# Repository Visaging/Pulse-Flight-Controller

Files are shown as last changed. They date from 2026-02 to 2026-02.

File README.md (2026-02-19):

# PULSE Flight Controller
## Why "Pulse"?
The name is inspired by two things I love:
1.  **Pulse Width Modulation (PWM):** The heartbeat signal that powers every motor in this drone.
2.  **Beatbox:** A personal touch (look at the silkscreen artwork on the top layer).

## Overview
Pulse is a completely custom flight controller that was created from the ground up. I designed the whole stack myself to truly understand how a drone works, from the low-level motor mixing logic to the physics of the gyroscope, even though it would have been simpler to simply rely on off-the-shelf hardware and Betaflight. The custom PCB designs and the particular STM32 firmware I wrote to make the silicon work are both included in this repository, which acts as documentation for that process.

## Hardware Stack
* **MCU:** **STM32F405RGT6** - Chosen because it's a beast at math and has enough pins for everything.
* **IMU:** **ICM-42688-P** - Newer and cleaner noise performance than the old MPU6000.
* **Barometer:** **BMP280** - for altitude hold.
* **Gimbal Drivers:** 2x **DRV8313** - integrated directly on the FC.
    * Instead of a heavy separate gimbal controller board, I built the drivers right onto the FC to save weight and space.
* **Power System:** - Redesigned buck converter using **LMR14030SDDAR**.
  * I initially designed it for 6S (25.2V), but realized I wanted headroom. The new design handles up to **40V** input.

## The Firmware
### Key Features:
* **1kHz Control Loop:** A strict real-time scheduler runs the physics engine every 1ms.
* **Quad-X Mixing:** Takes PID output and mathematically mixes it for the 4 motors using **TIM8** (Timer).
* **Interrupt driven I/O:** The Receiver (UART3) and Telemetry (UART4/5) run in the background via Interrupts, so the main flight loop never "freezes" waiting for data.
* **Smart Telemetry:** Streams live voltage, angles, and state to a **Raspberry Pi** companion computer.

### How to Flash It
I added a **USB-C port** and the "Holy Trinity" of buttons (BOOT + RESET) to the PCB so I don't need external dongles.
1.  Plug in USB-C.
2.  Hold **BOOT**.
3.  Click **RESET**.
4.  Release **BOOT**.
5.  Flash the `.bin` file using **STM32CubeProgrammer** (USB DFU Mode).

--- 
<details>
  <summary><h2>PCB Schematics</h2></summary>

</details>

---
<details>
  <summary><h2>PCB Layout and Render</h2></summary>

## Layout
#### Overall:


---
#### Top Layer:


---
#### Layer 2:


---
#### Layer 3:


---
#### Bottom Layer:


---
#### Front Silkscreen:


---
#### Back Silkscreen:


---
## Render
#### Front:


---
#### Back:

</details>

--- 
## Bill of Material

| Item | Description | Quantity | Unit Price ($) | Total Price ($) | URL | Running Total ($) |
| --- | --- | --- | --- | --- | --- | --- |
| PCBA | PCB | 5 PCB, 1 PCBA | $216.41 | $216.41 | https://www.lioncircuits.com/ | $216.41  |
| Tactile Switches  | Boot and Reset Buttons | 2 | $0.0363 | $0.0726 | https://robu.in/product/ts6610tp-160gf-bxg-022-shou-han-50ma-100m%cf%89-100000-times-12v-160gf-round-button-standing-paste-spst-smd-tactile-switches-rohs/ | $216.4826 |
| TYPE-C-31-M-12 | USB-C Port | 1 | $0.42 | $0.42 | https://www.lioncircuits.com/ | $216.9026 |

<details>
  <summary>JLCPCB Order</summary>




</details>
<details>
  <summary>Lion Circuit Order</summary>

final
Lion Circuits_Page_1
</details>
<details>
   
  <summary>Cart</summary>


</details>

## Lessons Learned
* **Power is hard:** My first schematic had a buck converter that would have fried on a 6S battery. Catching that mistake saved the project.
* **Routing matters:** Moving to 4 layers was scary at first, but it solved all my noise and heat issues.
* **Code vs. Reality:** Writing the firmware forced me to verify every single pin connection. I found out that "polling" a receiver is too slow, so I had to learn how Interrupts work.

## License: MIT

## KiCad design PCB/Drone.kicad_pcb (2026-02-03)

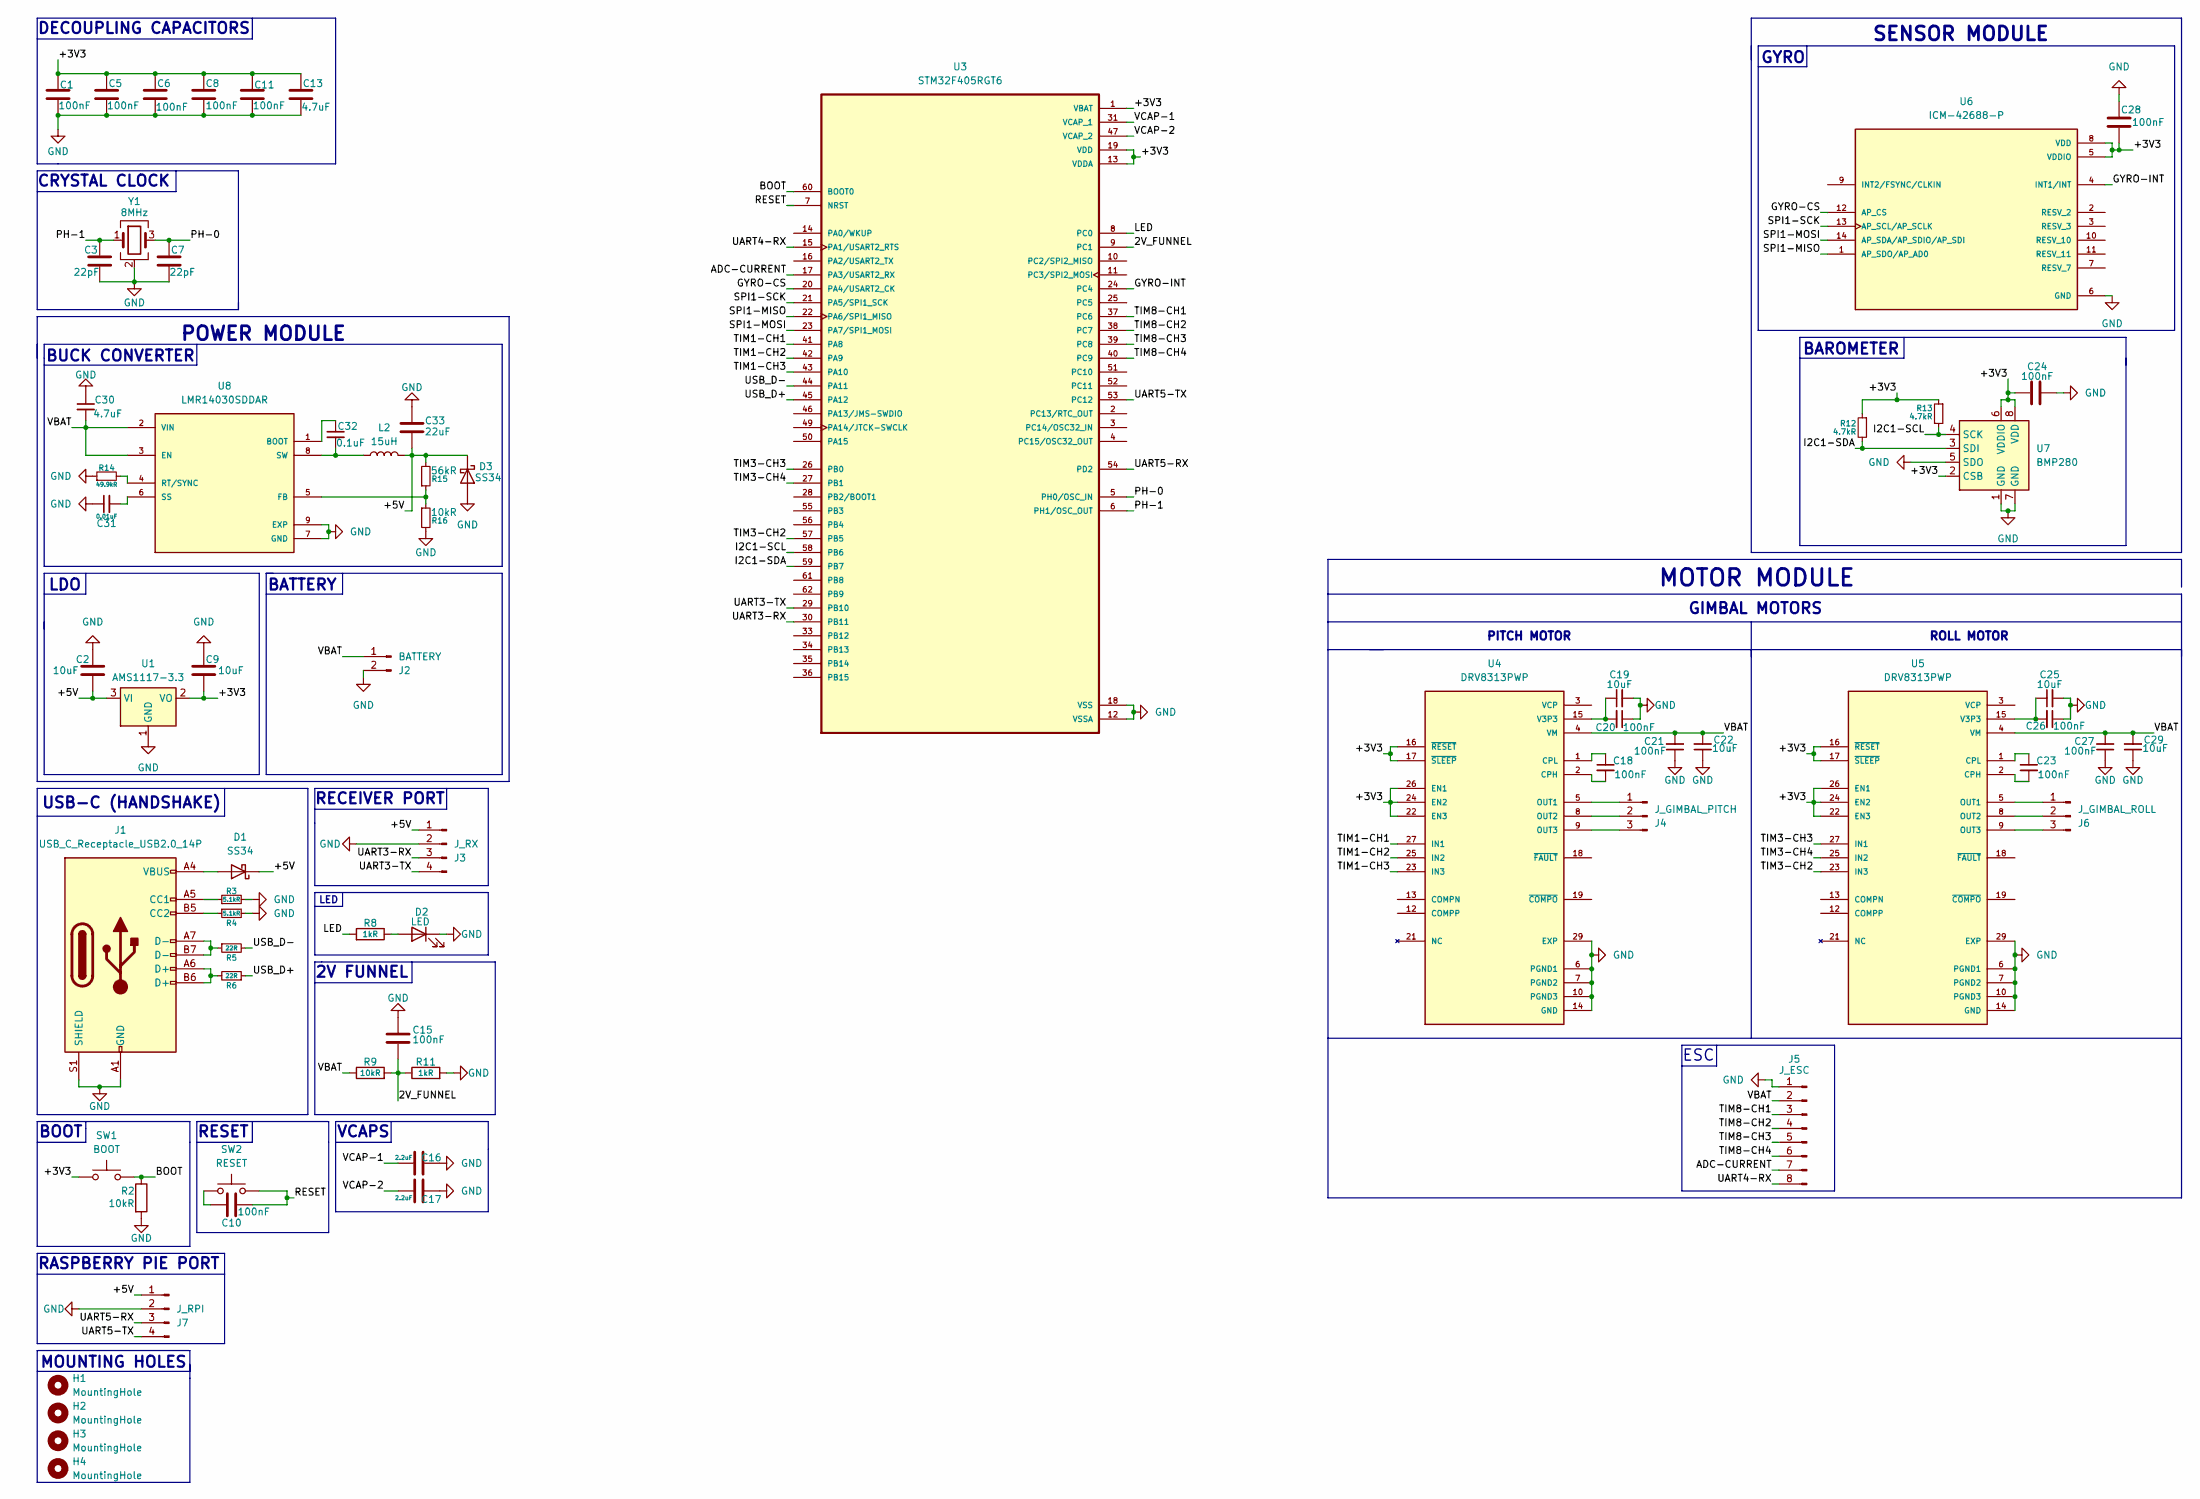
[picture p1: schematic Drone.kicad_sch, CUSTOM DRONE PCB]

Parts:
C1, C5, C6, C8, C10, C11, C15, C18, C20, C23, C24, C26, C28: 100nF; C_0603_1608Metric
C2, C9, C19, C25: 10uF; C_0603_1608Metric
C3, C7: 22pF; C_0603_1608Metric
C13: 4.7uF; C_0603_1608Metric
C16, C17: 2.2uF; C_0603_1608Metric
C21, C27: 100nF; C_1206_3216Metric
C22, C29: 10uF; C_1206_3216Metric
C30: 4.7uF; C_1210_3225Metric
C31: 0.01uF; C_0603_1608Metric
C32: 0.1uF; C_0603_1608Metric
C33: 22uF; C_1206_3216Metric
D1, D3: SS34; D_SMA
D2: LED; LED_0805_2012Metric
H1, H2, H3, H4: MountingHole; MountingHole_3.2mm_M3
J1: USB_C_Receptacle_USB2.0_14P; USB_C_Receptacle_HRO_TYPE-C-31-M-12
J2: BATTERY; SolderWire-2.5sqmm_1x02_P7.2mm_D2.4mm_OD3.6mm
J3: J_RX; PinHeader_1x04_P2.54mm_Vertical
J4: J_GIMBAL_PITCH; SolderWire-0.75sqmm_1x03_P4.8mm_D1.25mm_OD2.3mm
J5: J_ESC; PinHeader_1x08_P2.54mm_Vertical
J6: J_GIMBAL_ROLL; SolderWire-0.75sqmm_1x03_P4.8mm_D1.25mm_OD2.3mm
J7: J_RPI; SolderWire-0.1sqmm_1x04_P3.6mm_D0.4mm_OD1mm
L2: 15uH; L_Bourns_SRN6045TA
R2, R9: 10kR; R_0603_1608Metric
R3, R4: 5.1kR; R_0603_1608Metric
R5, R6: 22R; R_0603_1608Metric
R8, R11: 1kR; R_0603_1608Metric
R12, R13: 4.7kR; R_0603_1608Metric
R14: 49.9kR; R_0805_2012Metric
R15: 56kR; R_0805_2012Metric
R16: 10kR; R_0805_2012Metric
SW1: BOOT; SW_SPST_PTS645Sx43SMTR92
SW2: RESET; SW_SPST_PTS645Sx43SMTR92
U1: AMS1117-3.3; SOT-223-3_TabPin2
U3: STM32F405RGT6; QFP50P1200X1200X160-64N; PARTREV LTR
U4, U5: DRV8313PWP; SOP65P640X120-29N; PARTREV D
U6: ICM-42688-P; PQFN50P300X250X97-14N; PARTREV 1.2
U7: BMP280; Bosch_LGA-8_2x2.5mm_P0.65mm_ClockwisePinNumbering
U8: LMR14030SDDAR; SOIC127P600X170-9N; PARTREV A
Y1: 8MHz; Crystal_SMD_3225-4Pin_3.2x2.5mm

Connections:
/2V_FUNNEL: C15.2, R9.2, R11.1, U3.9 (PC1)
/+5V: C2.2, C33.2, D1.1 (K), D3.1 (K), J3.1, J7.1, L2.2, R15.2, U1.3 (VI)
/ADC-CURRENT: J5.7, U3.17 (PA3/USART2_RX)
/BOOT: R2.1, SW1.2, U3.60 (BOOT0); also elsewhere on the board
/GYRO-CS: U3.20 (PA4/USART2_CK), U6.12 (AP_CS)
/GYRO-INT: U3.24 (PC4), U6.4 (INT1/INT)
/I2C1-SCL: R13.2, U3.58 (PB6), U7.4 (SCK)
/I2C1-SDA: R12.2, U3.59 (PB7), U7.3 (SDI)
/LED: R8.2, U3.8 (PC0)
/PH-0: C7.1, U3.5 (PH0/OSC_IN), Y1.3
/PH-1: C3.1, U3.6 (PH1/OSC_OUT), Y1.1
/RESET: C10.2, SW2.2, U3.7 (NRST); also elsewhere on the board
/SPI1-MISO: U3.22 (PA6/SPI1_MISO), U6.1 (AP_SDO/AP_AD0)
/SPI1-MOSI: U3.23 (PA7/SPI1_MOSI), U6.14 (AP_SDA/AP_SDIO/AP_SDI)
/SPI1-SCK: U3.21 (PA5/SPI1_SCK), U6.13 (AP_SCL/AP_SCLK)
/TIM1-CH1: U3.41 (PA8), U4.27 (IN1)
/TIM1-CH2: U3.42 (PA9), U4.25 (IN2)
/TIM1-CH3: U3.43 (PA10), U4.23 (IN3)
/TIM3-CH2: U3.57 (PB5), U5.23 (IN3)
/TIM3-CH3: U3.26 (PB0), U5.27 (IN1)
/TIM3-CH4: U3.27 (PB1), U5.25 (IN2)
/TIM8-CH1: J5.3, U3.37 (PC6)
/TIM8-CH2: J5.4, U3.38 (PC7)
/TIM8-CH3: J5.5, U3.39 (PC8)
/TIM8-CH4: J5.6, U3.40 (PC9)
/UART3-RX: J3.3, U3.30 (PB11)
/UART3-TX: J3.4, U3.29 (PB10)
/UART4-RX: J5.8, U3.15 (PA1/USART2_RTS)
/UART5-RX: J7.3, U3.54 (PD2)
/UART5-TX: J7.4, U3.53 (PC12)
/USB_D+: R6.1, U3.45 (PA12)
/USB_D-: R5.2, U3.44 (PA11)
/VCAP-1: C16.1, U3.31 (VCAP_1)
/VCAP-2: C17.1, U3.47 (VCAP_2)
GND: C1.2, C2.1, C3.2, C5.2, C6.2, C7.2, C8.2, C9.1, C11.2, C13.2, C15.1, C16.2, C17.2, C19.2, C20.1, C21.1, C22.1, C24.1, C25.2, C26.1, C27.1, C28.1, C29.1, C30.1, C31.1, C33.1, D2.1 (K), D3.2 (A), J1.A1 (GND), J1.A12 (GND), J1.B1 (GND), J1.B12 (GND), J1.S1 (SHIELD), J2.2, J3.2, J5.1, J7.2, R2.2, R3.2, R4.2, R11.2, R14.1, R16.2, U1.1 (GND), U3.12 (VSSA), U3.18 (VSS), U3.63 (VSS), U4.6 (PGND1), U4.7 (PGND2), U4.10 (PGND3), U4.14 (GND), U4.20 (GND), U4.28 (GND), U4.29 (EXP), U5.6 (PGND1), U5.7 (PGND2), U5.10 (PGND3), U5.14 (GND), U5.20 (GND), U5.28 (GND), U5.29 (EXP), U6.6 (GND), U7.1 (GND), U7.5 (SDO), U7.7 (GND), U8.7 (GND), U8.9 (EXP), U8.V1 (EXP), U8.V2 (EXP), U8.V3 (EXP), U8.V4 (EXP), U8.V5 (EXP), U8.V6 (EXP), Y1.2 (G), Y1.4 (G)
unnamed 35: C10.1, SW2.1; also elsewhere on the board
unnamed: D1.2 (A), J1.A4 (VBUS), J1.A9 (VBUS), J1.B4 (VBUS), J1.B9 (VBUS)
unnamed: D2.2 (A), R8.1
unnamed: J1.A5 (CC1), R3.1
unnamed: J1.B5 (CC2), R4.1
unnamed: J1.A6 (D+), J1.B6 (D+), R6.2
unnamed: J1.A7 (D-), J1.B7 (D-), R5.1
unnamed 42: J4.1, U4.5 (OUT1); also elsewhere on the board
unnamed 43: J4.2, U4.8 (OUT2); also elsewhere on the board
unnamed 44: J4.3, U4.9 (OUT3); also elsewhere on the board
unnamed 45: J6.1, U5.5 (OUT1); also elsewhere on the board
unnamed 46: J6.2, U5.8 (OUT2); also elsewhere on the board
unnamed 47: J6.3, U5.9 (OUT3); also elsewhere on the board
unnamed: C18.2, U4.2 (CPH)
unnamed: C18.1, U4.1 (CPL)
unnamed: C19.1, C20.2, U4.15 (V3P3)
unnamed: C23.2, U5.2 (CPH)
unnamed: C23.1, U5.1 (CPL)
unnamed: C25.1, C26.2, U5.15 (V3P3)
unnamed: C32.1, U8.1 (BOOT)
unnamed: R15.1, R16.1, U8.5 (FB)
unnamed: R14.2, U8.4 (RT/SYNC)
unnamed: C31.2, U8.6 (SS)
unnamed: C32.2, L2.1, U8.8 (SW)
VDD: C1.1, C5.1, C6.1, C8.1, C9.2, C11.1, C13.1, C24.2, C28.2, R12.1, R13.1, SW1.1, U1.2 (VO), U3.1 (VBAT), U3.13 (VDDA), U3.19 (VDD), U3.32 (VDD), U3.48 (VDD), U3.64 (VDD), U4.16 (~RESET), U4.17 (~SLEEP), U4.22 (EN3), U4.24 (EN2), U4.26 (EN1), U5.16 (~RESET), U5.17 (~SLEEP), U5.22 (EN3), U5.24 (EN2), U5.26 (EN1), U6.5 (VDDIO), U6.8 (VDD), U7.2 (CSB), U7.6 (VDDIO), U7.8 (VDD); also elsewhere on the board
VM: C21.2, C22.2, C27.2, C29.2, C30.2, J2.1, J5.2, R9.1, U4.4 (VM), U4.11 (VM), U5.4 (VM), U5.11 (VM), U8.2 (VIN), U8.3 (EN)

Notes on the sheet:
RECEIVER PORT
BAROMETER
GIMBAL MOTORS
VCAPS
LED
BUCK CONVERTER
ESC
RESET
GYRO
CRYSTAL CLOCK
RASPBERRY PIE PORT
ROLL MOTOR
DECOUPLING CAPACITORS
PITCH MOTOR
LDO
2V FUNNEL
MOUNTING HOLES
BOOT
SENSOR MODULE
BATTERY
POWER MODULE
USB-C (HANDSHAKE)
MOTOR MODULE

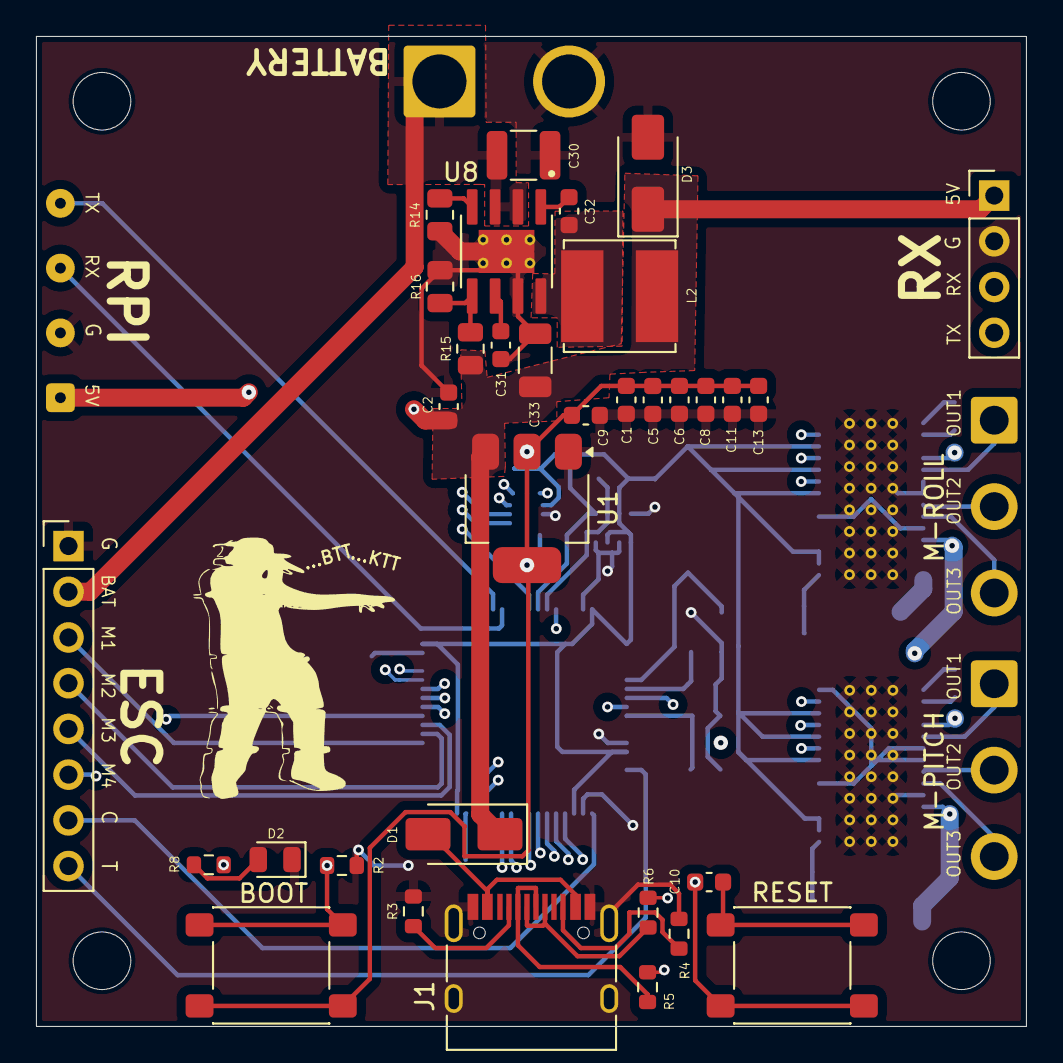
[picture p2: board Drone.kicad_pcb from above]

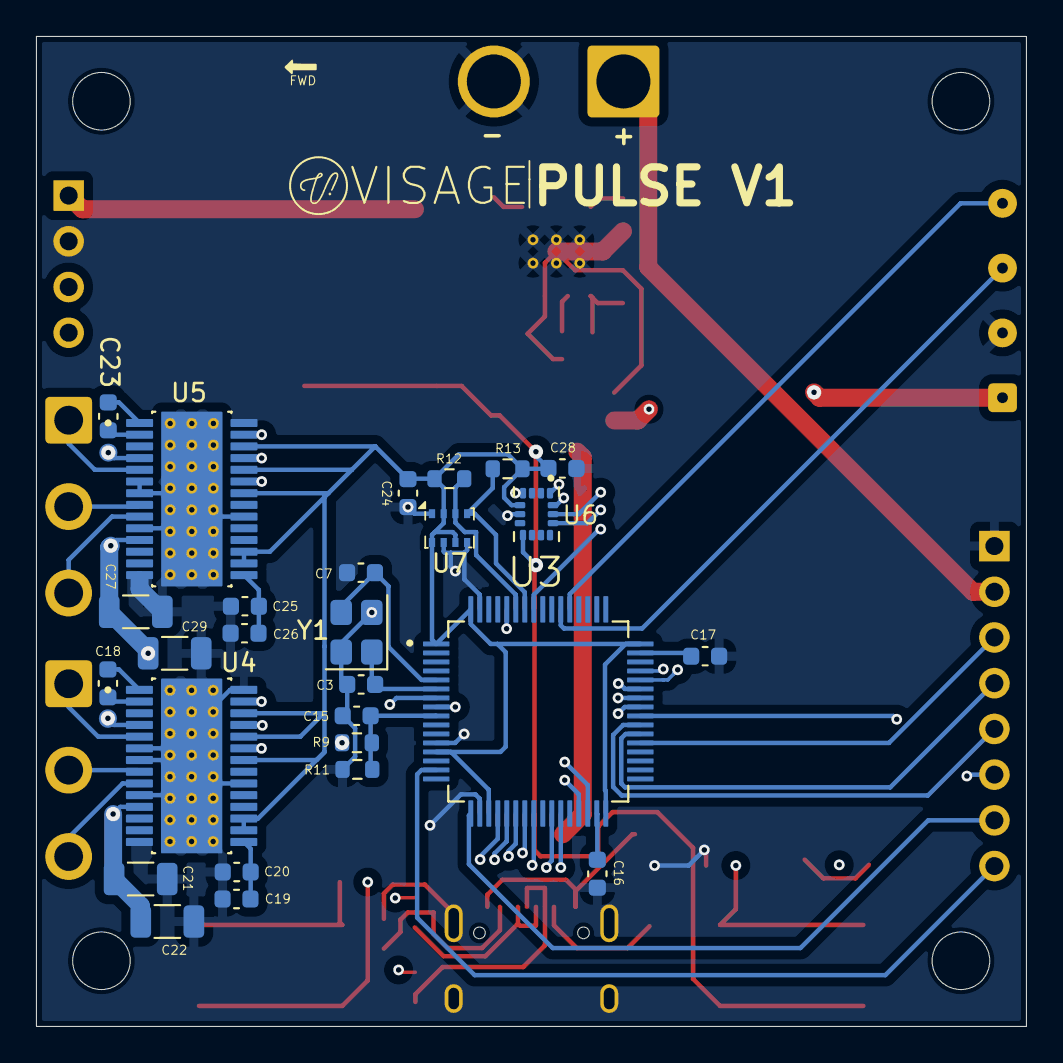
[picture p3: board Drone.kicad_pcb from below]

Board: 4 copper layers, 55.0 x 55.0 mm, 68 parts (27 on the bottom side), 61 nets.

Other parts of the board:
BOOT: BOOT; SW_SPST_PTS645Sx43SMTR92
M-PITCH: J_GIMBAL_PITCH; SolderWire-0.75sqmm_1x03_P4.8mm_D1.25mm_OD2.3mm
M-ROLL: J_GIMBAL_ROLL; SolderWire-0.75sqmm_1x03_P4.8mm_D1.25mm_OD2.3mm
RESET: RESET; SW_SPST_PTS645Sx43SMTR92

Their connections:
/BOOT: BOOT.2; also elsewhere on the board
/RESET: RESET.2; also elsewhere on the board
unnamed 35: RESET.1; also elsewhere on the board
unnamed 42: M-PITCH.1; also elsewhere on the board
unnamed 43: M-PITCH.2; also elsewhere on the board
unnamed 44: M-PITCH.3; also elsewhere on the board
unnamed 45: M-ROLL.1; also elsewhere on the board
unnamed 46: M-ROLL.2; also elsewhere on the board
unnamed 47: M-ROLL.3; also elsewhere on the board
VDD: BOOT.1; also elsewhere on the board
